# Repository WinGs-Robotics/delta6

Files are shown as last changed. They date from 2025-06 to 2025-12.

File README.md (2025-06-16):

# Delta6: 6-DOF Force-Sensing Flexible End-Effector

<div align="center">
  Delta6 in Action
</div>

---

## 🚀 Overview

**Delta6** is a **low-cost**, **lightweight**, and **easy-to-assemble** 6-degree-of-freedom (6-DOF) flexible end-effector. Built upon an innovative modified Delta parallel mechanism, it integrates:

- **Six antagonistic spring units** for high-resolution force sensing.
- Real-time multi-axis force and displacement measurements.
- Built-in analytical compensation algorithms, correcting for imperfections from **3D-printed parts** and **commercial springs**.

Its inherent compliance makes Delta6 ideal for interactive tasks such as human–robot collaboration, precision assembly, and delicate manipulation.

---

## 📐 Specifications

<div align="center">
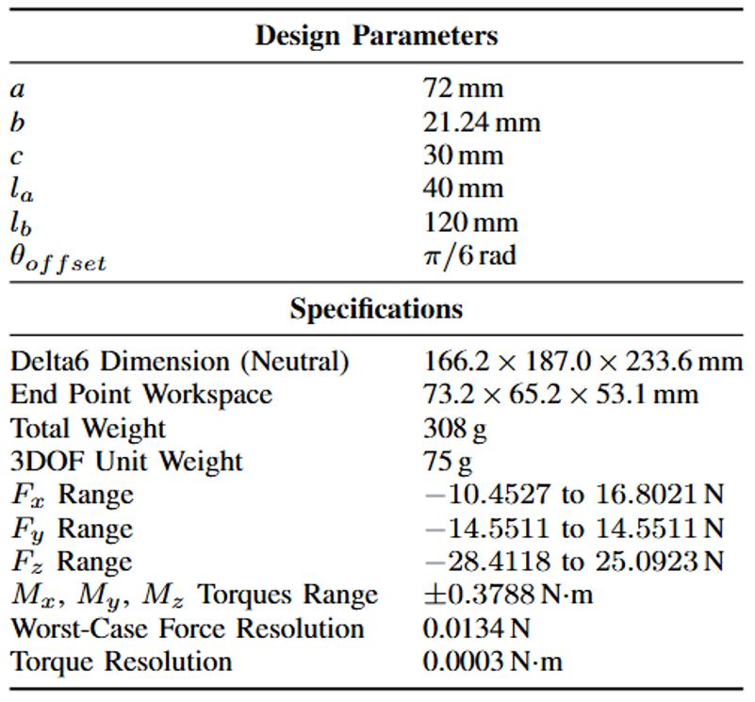
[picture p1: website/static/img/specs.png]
Delta6 Specifications
  
</div>

- **Compact & Lightweight:** ~170 × 190 × 235 mm, < 310 grams.
- **Operational Workspace:** Tens of millimeters range in all directions.
- **Force & Torque:** ±15 N forces, ±0.4 N·m torques.
- **High Precision:** Resolution down to hundredths of a newton and thousandths of a newton-meter.

---

## 📋 Bill of Materials

| Component | Quantity | Unit Cost (USD) | Subtotal (USD) |
|---|:---:|:---:|---:|
| PLA Filament (200 g) | 1 | 3.00 | **3.00** |
| Arduino Nano Every | 1 | 13.00 | **13.00** |
| M2 Tie-Rod Ball Ends | 12 | 1.00 | **12.00** |
| M2 × 100 mm Threaded Rods | 6 | 2.00 | **12.00** |
| Mn-Steel Door Handle Springs | 12 | 2.00 | **24.00** |
| ERCK-05 SPI 14-bit Magnetic Encoders | 6 | 43.00 | **258.00** |
| 15 × 21 × 4 mm Ball Bearing | 1 | 1.00 | **1.00** |
| 8 × 12 × 3.5 mm Ball Bearings | 10 | 1.00 | **10.00** |
| Wires, Connectors & Fasteners | Various  | 1.00 | **1.00** |
| **Total Cost** | | | **US $334.00** |

---

## 🔓 Open-Source Highlights

### 🧠 Analytical Force Estimation
Effortlessly translate encoder readings into a **complete 6-DOF wrench**, requiring simple calibration and enabling high-frequency computation on standard microcontrollers or PCs.

### ⚙️ Modular & 3D-Printable
Engineered specifically for **consumer-grade PLA printers**, Delta6 features only **13 unique, symmetrically-arranged parts**, simplifying both manufacturing and assembly.

### 💰 Cost-Effective
Prototype costs are approximately **$300 USD**, with further reductions achievable through bulk production and custom PCB integration.

---

## 🚧 Getting Started

Detailed purchase links, comprehensive CAD models, intuitive assembly instructions, firmware, and a Python SDK are available in DOC website. Start building your Delta6 today and explore the possibilities of affordable, precise robotic interaction!

---

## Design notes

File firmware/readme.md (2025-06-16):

# Delta6 Firmware Communication Protocol

## Overview

This document describes the communication protocol between the PC (host) and the Delta6 end-effector firmware, including command formats, response formats, functional descriptions, and error handling mechanisms.

---

## 📱 Command Frame Format (PC → Firmware)

| Field | Description |
|:---:|:---:|
| Start Byte | `0xAA`, indicates the beginning of a frame |
| Command Byte | Operation code (Calibration or Read) |
| Checksum | Simple additive checksum |

**Command Byte Values**:
- `0x01`: **Calibration Command**
- `0x02`: **Read Command**

**Checksum**:  
The checksum is calculated as the simple sum of the start byte and command byte, modulo 256.

---

## 📥 Response Frame Format (Firmware → PC)

| Field | Description |
|:---:|:---:|
| Start Byte | `0xAA`, indicates the beginning of a frame |
| Sensor 1 Data | 2 bytes (signed integer, calibrated angle) |
| ... | ... |
| Sensor 6 Data | 2 bytes (signed integer, calibrated angle) |
| Error Flags | 1 byte (each bit indicates a sensor read error) |
| Checksum | 1 byte (simple additive checksum) |

**Sensor Data**:  
Each sensor outputs a signed 2-byte integer representing the calibrated angle.

**Error Flags**:  
- 1 byte total.
- Each bit corresponds to one sensor.  
  If a bit is `1`, the corresponding sensor encountered a read error.

**Checksum**:  
The checksum is calculated as the simple sum of all bytes after the start byte.

---

## 🔧 Functional Details

### Calibration Function

Upon receiving a **Calibration Command (0x01)**, the firmware:
- Reads the current angle values from all sensors.
- Stores them as calibration offsets.

### Read Function

Upon receiving a **Read Command (0x02)**, the firmware:
- Reads the current sensor values.
- Subtracts calibration offsets.
- Sends the calibrated values along with error flags and checksum.

### Error Handling

In the `updatePositions()` function:
- If a sensor read returns `-1`, the corresponding error flag bit is set.
- Errors are reported in the response frame's error flag byte.

### Data Integrity

- A simple additive checksum ensures data integrity.
- CRC can be used for more robust error detection if needed.

---

## 📌 Notes

- Start byte `0xAA` must always be included at the beginning of each frame.
- Only two commands (`0x01` and `0x02`) are currently supported.
- All multi-byte data are transmitted **big-endian** unless otherwise specified.

---

✅ **This communication protocol ensures reliable, efficient interaction between the PC and the Delta6 firmware, enabling robust 6-DOF force-sensing operations.**

## Acknowledgment

**Some parts of the documentation and code were assisted by language models (OpenAI's ChatGPT) during their initial drafting. All content was subsequently reviewed and verified by the project authors.**

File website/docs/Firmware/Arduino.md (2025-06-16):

---
sidebar_position: 1
---

# Microcontroller Setup 🖥️

This section explains how to set up the Arduino Nano Every and prepare the Python environment for the Delta6 system.

> 📦 **Firmware Repository:**  
> The firmware code for the Arduino Nano Every is available here:  
> [Delta6 Firmware on GitHub](https://github.com/ttopeor/Delta6_Doc/tree/main/firmware)

---

## 1. Download the Repository

Clone the Delta6 project repository:

```bash
git clone https://github.com/ttopeor/Delta6_Doc.git
```

---

## 2. Create and Activate Python Environment

Navigate to the Python SDK folder:

```bash
cd delta6_python_SDK
```

> 📌 **Tip:** Ensure that Python 3.12 is installed on your system.

Create a virtual environment:

```bash
python3.12 -m venv venv
```

Activate the virtual environment:

- **On Ubuntu:**

  ```bash
  source venv/bin/activate
  ```

- **On Windows:**
  ```bash
  source venv/Scripts/activate
  ```

Install all required dependencies:

```bash
pip install -e .
```

---

## 3. Burn Firmware to Arduino

Check the COM port (for example `/dev/ttyACM0` on Linux) where your Arduino Nano Every is connected.  
Then run the following command:

```bash
python burn_firmware.py --port /dev/ttyACM0
```

> 🧩 **Tip:** Adjust the `--port` argument according to your specific system setup.

---

## 4. Verify Operation

Run the example script:

```bash
python example.py --port /dev/ttyACM0
```

If successful, a window should pop up similar to:

<p align="center">
  Online Evaluation
</p>

The coordinate system is defined as follows:

<p align="center">
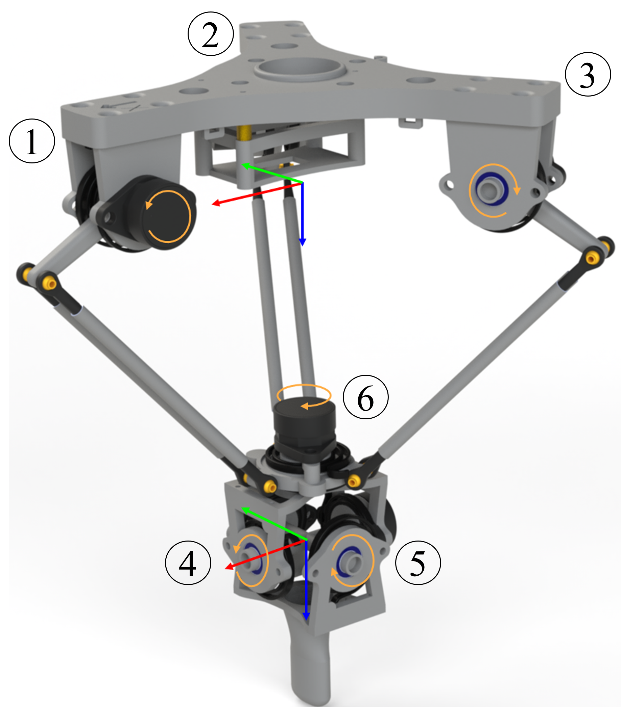
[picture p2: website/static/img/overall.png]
Coordinate System Definition
  
</p>

---

🎯 **Congratulations!**  
Your microcontroller setup is complete, and the Delta6 system is ready for further testing and calibration.

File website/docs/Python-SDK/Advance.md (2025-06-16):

---
sidebar_position: 3
---

# Advanced Usage 🚀

This section provides a detailed explanation of the **DeltaRobot** class located at:

```bash
delta6_python_SDK/kinematics/delta6_analytics.py
```

The `DeltaRobot` class offers methods for advanced kinematics calculations, force estimation, and internal torque computations for the Delta6 system.

---

## 1. Initialization

Create a Delta6 robot model by specifying its physical parameters:

```python
from kinematics.delta6_analytics import DeltaRobot

delta6 = DeltaRobot(
    short_arm_length=40.0,         # Length of the short (servo) arm [mm]
    parallel_arm_length=120.0,     # Length of the parallel (linkage) arm [mm]
    base_radius=72.0,              # Radius of the fixed base [mm]
    end_effector_radius=21.24      # Radius of the moving end-effector platform [mm]
)
```

> 📌 **Note:** Default values are already tuned for the Delta6 system.

---

## 2. Main Interfaces

### 2.1 Updating Joint States

You can update the robot's internal state (angles and torques) using:

```python
delta6.update(theta1, theta2, theta3, theta4, theta5, theta6)
```

- `theta1` to `theta6` are joint angles (in radians).
- Internally, it updates both joint angles and spring torques.

---

### 2.2 Forward Kinematics

To compute the end-effector pose (position and orientation) from joint angles:

```python
pose = delta6.get_FK_result()
```

Returns a tuple:

```
(x, y, z, roll, pitch, yaw)
```
- All positions are in meters (m).
- All rotations are in radians (rad).

> 📌 **Tip:** The Delta6 model internally handles the mechanical offsets and link geometry.

---

### 2.3 Inverse Kinematics

To solve the required joint angles for a given target pose:

```python
thetas = delta6.inverse_kinematics(x, y, z, roll, pitch, yaw)
```

- Input: desired position (m) and orientation (rad).
- Output: six joint angles `(theta1, theta2, theta3, theta4, theta5, theta6)`.
- Returns `None` if the target is unreachable.

---

### 2.4 Force Estimation

To estimate the end-effector force/torque from spring readings:

```python
force = delta6.get_end_force()
```

Returns a tuple:

```
(Fx, Fy, Fz, Mx, My, Mz)
```
- Forces are in Newtons (N).
- Moments are in Newton-meters (Nm).

Internally, it uses the joint torques and geometric Jacobians.

---

### 2.5 Force-to-Torque Mapping

Given a desired force vector at the end-effector, you can calculate the required torques:

```python
torques = delta6.calculate_torque_123(Fx_target, Fy_target, Fz_target)
```

Useful for simulating force control.

---

### 2.6 Force-to-Pose Mapping

Given a full 6-DOF wrench `(Fx, Fy, Fz, Mx, My, Mz)`, estimate the corresponding pose:

```python
pose = delta6.calculate_euler_pose(Fx, Fy, Fz, Mx, My, Mz)
```

Returns:

```
(x, y, z, roll, pitch, yaw)
```

This is useful for **force-sensitive end-effector control** based on spring torque feedback.

---

## 3. Internal Model Details

> ⚙️ **Mechanics:**
> 
> - The Delta6 kinematics assumes 3 symmetric legs.
> - It internally applies mechanical z-offset corrections.
> - Rotations are handled using **scipy.spatial.transform** Euler conversion utilities.
> 
> - Forces are estimated based on spring extension/compression, taking into account the Delta geometry.

---

## 4. Summary

| Function | Purpose |
| :--- | :--- |
| `update()` | Update joint angles and compute torques |
| `get_FK_result()` | Compute end-effector pose from joint states |
| `inverse_kinematics()` | Solve joint states from target pose |
| `get_end_force()` | Estimate forces and moments |
| `calculate_torque_123()` | Map desired forces to spring torques |
| `calculate_euler_pose()` | Map desired forces/moments to end-effector pose |

---

🎯 **Advanced Tip:**  
You can combine real-time encoder readings + `update()` + `get_end_force()` to build a **real-time force estimation loop**, enabling force-controlled teleoperation or haptic feedback applications.

---

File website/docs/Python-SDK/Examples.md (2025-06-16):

---
sidebar_position: 2
---

# Quick Start Examples 💡

This section provides a quick guide on how to run a basic real-time loop using the Delta6 Python SDK.

The example script is located at:

```bash
delta6_python_SDK/example.py
```

---

## 1. Purpose of This Example

The `example.py` script demonstrates:

- Calibrating the sensors
- Reading encoder data in real-time
- Computing forward kinematics
- Visualizing the estimated end-effector forces

It serves as a **minimal starting point** to verify that all hardware and software are working correctly.

---

## 2. How to Run

Activate the Python environment first:

```bash
# On Ubuntu
source venv/bin/activate

# On Windows
source venv/Scripts/activate
```

Then run the example:

```bash
python delta6_python_SDK/example.py --port /dev/ttyACM0 --freq 50
```

- Replace `/dev/ttyACM0` with your Arduino Nano Every's actual port.
- `--freq` controls the loop frequency (default is 50 Hz).

---

## 3. How It Works

The script defines a `MainLoop` class (derived from `RTLoop`) to organize initialization, looping, and shutdown behaviors.

The full execution flow is as follows:

### Initialization (`setup()` method)

1️⃣ **Sensor Calibration**  
   - Code: `sensor_calibration(nano_port=self.nano_port)`
   - Prompts the user to move the device to a neutral position and records zero offsets.

2️⃣ **Start Encoder Reading Loop**  
   - Code: `self.read_encoder_loop = ReadEncoderLoop(nano_port=self.nano_port, encoder_dir=ENCODER_DIR)`
   - Encoder angles are read asynchronously at high frequency.

3️⃣ **Initialize Delta6 Kinematics Model**  
   - Code: `self.Delta6 = DeltaRobot()`
   - Creates a new DeltaRobot instance to calculate forward kinematics from encoder readings.

4️⃣ **Start Force Visualizer**  
   - Code: 
     ```python
     self.force_visualizer = ForceVisualizer(...)
     self.force_visualizer.start()
     ```
   - A real-time window opens to display the estimated end-effector forces.

5️⃣ **Start Real-Time Loop Spin**  
   - Code: `super().setup()`
   - Prepares the internal threading/timing logic to start looping.

---

### Main Loop (`loop()` method)

Each real-time cycle (`50 Hz` by default):

- **Read encoder data**  
  Code: `encoder_reading = self.read_encoder_loop.get_encoder_reading()`

- **Update Delta6 model**  
  Code: `self.Delta6.update(*encoder_reading)`

- **Compute and print end-effector pose**  
  Code: 
  ```python
  delta6_pose_reading = self.Delta6.get_FK_result()
  print(f"End-effector pose (x, y, z, roll, pitch, yaw): {delta6_pose_reading}")
  ```

- **Update the force visualizer**  
  Code:
  ```python
  delta6_end_force = self.Delta6.get_end_force()
  self.force_visualizer.update_forces([delta6_end_force])
  ```

Example console output:

```
End-effector pose (x, y, z, roll, pitch, yaw): [0.012, 0.005, 0.230, 0.01, -0.02, 0.00]
```

---

### Shutdown (`shutdown()` method)

When exiting the program (e.g., Ctrl+C):

- **Stop the force visualizer**  
  Code: `self.force_visualizer.stop()`

- **Terminate real-time loop cleanly**  
  Code: `super().shutdown()`

- **Print shutdown confirmation**  
  Code: `print("Force visualizer shutdown.")`

---

## 4. Notes

> 📌 **Tip:**  
You can adjust the `--freq` parameter to higher values (e.g., 100 Hz) for faster updates, depending on your PC performance.

> ⚡ **Warning:**  
Always run sensor calibration before starting meaningful data collection, to avoid force/pose estimation errors.

---

🎯 **Congratulations!**  
By running this quick start example, you have verified that your Delta6 system hardware and software are properly set up!

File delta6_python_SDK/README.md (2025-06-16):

## 📘 Quick Start Guide

### 1. Setup Python Environment
```bash
cd delta6_python_SDK
python3.12 -m venv venv

# Activate virtual environment
# On Ubuntu
source venv/bin/activate

# On Windows
source venv/Scripts/activate

pip install -e .
```

### 2. Burn Firmware to Arduino Nano
```bash
python burn_firmware.py --port /dev/ttyACM0
```

### 3. Run Example
```bash
python example.py --port /dev/ttyACM0
```

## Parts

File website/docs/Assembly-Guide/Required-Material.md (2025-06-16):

---
sidebar_position: 1
---

# Required Material & Tools 📦

This page provides a detailed list of all required materials and tools to assemble the Delta6 system.

---

## 1. 3D Printed Parts 🖨️

All CAD files are available at:  
🔗 [Delta6 CAD Repository](https://github.com/ttopeor/Delta6_Doc/tree/main/CAD)

<p align="center">
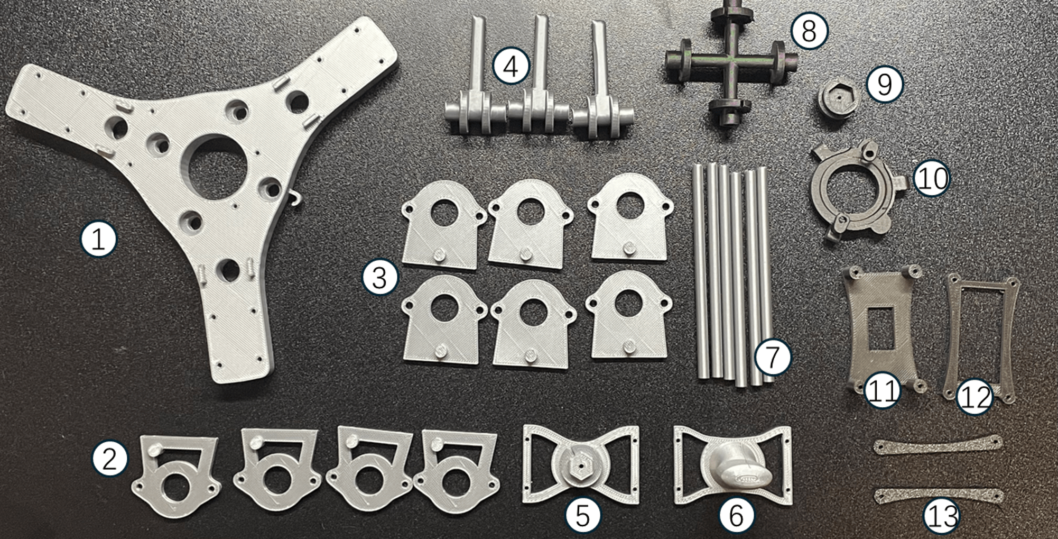
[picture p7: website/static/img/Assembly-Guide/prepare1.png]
3D Printed Parts
  
</p>

The following parts need to be 3D printed using **PLA** material:

| No. | Part Name | File Name | Quantity |
| :-: | :--- | :--- | :--- |
|  1  | Arm Mount | `arm_mount.STL` | 1 |
|  2  | Bearing Housing (Roll/Pitch) | `bearing_housing_roll_pitch.STL` | 4 |
|  3  | Bearing Housing (XYZ) | `bearing_housing_xyz.STL` | 6 |
|  4  | Limb | `limb.STL` | 3 |
|  5  | Universal Joint (Upper) | `universal_joint_upper.STL` | 1 |
|  6  | Universal Joint (Lower) | `universal_joint_lower.STL` | 1 |
|  7  | Long M2 Cover | `long_m2_cover.STL` | 6 |
|  8  | Shaft (Roll/Pitch) | `shaft_roll_pitch.STL` | 1 |
|  9  | Shaft (Yaw) | `shaft_yaw.STL` | 1 |
| 10  | Bearing Housing (Yaw) | `bearing_housing_yaw.STL` | 1 |
| 11  | Power Distributor Holder | `power_distributor_holder.STL` | 1 |
| 12  | Nano Holder 1 | `nano_holder_1.STL` | 1 |
| 13  | Nano Holder 2 | `nano_holder_2.STL` | 1 |

> 📌 **Note:** Please ensure sufficient print quality (recommended infill = 100%) for mechanical robustness.

---

## 2. Standard Components 🔩

<p align="center">
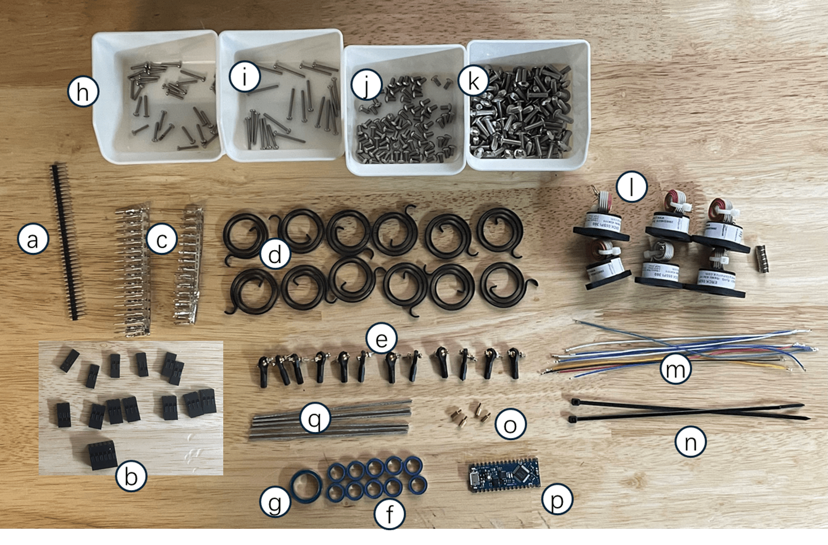
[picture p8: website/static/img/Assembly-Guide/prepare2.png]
Standard Parts Overview
  
</p>

The following standard parts must be prepared:

| No. | Component | Link | Quantity |
| :-- | :--- | :--- | :--- |
| a | GPIO Pins | [Amazon](https://www.amazon.com/MCIGICM-Header-2-45mm-Arduino-Connector/dp/B07PKKY8BX/) | 1 Row |
| b/c | 2.54mm Connector Kit | [Amazon](https://www.amazon.com/dp/B077X8XV2J) | 2-pin (6 pcs), 3-pin (7 pcs), 2×6-pin (1 pc) |
| d | Coil Springs | [Amazon](https://www.amazon.com/dp/B07ZVJR1HM) | 6 pcs |
| e | M2 Ball Heads | [Amazon](https://www.amazon.com/dp/B0BJFLD8RH) | 12 pcs |
| f | Bearings (8×12×3.5mm) | [Amazon](https://www.amazon.com/dp/B09L13V474) | 10 pcs |
| g | Bearings (15×21×4mm) | [Amazon](https://www.amazon.com/dp/B09L11PJJN) | 1 pc |
| h | M2×8mm Screws | [Amazon](https://www.amazon.com/iExcell-Stainless-Steel-Socket-Screws/dp/B094NVN97P/) | As needed |
| i | M2×20mm Screws | [Amazon](https://www.amazon.com/iexcell-Stainless-Steel-Socket-Screws/dp/B0B4VS4PCK/) | As needed |
| j | M3×6mm Screws | [Amazon](https://www.amazon.com/Uxcell-a15070200ux0064-Stainless-Phillips-Screws/dp/B012TE12CY/) | As needed |
| k | M4×6mm Screws | [Amazon](https://www.amazon.com/uxcell-Machine-Phillips-Stainless-Fasteners/dp/B07MF33MRJ) | As needed |
| l | ERCK 05SPI 360 Encoders | [P3 America](https://p3america.com/erck-05spi-360/) | 6 pcs |
| m | Colored 28 AWG Cables | [Amazon](https://www.amazon.com/Keszoox-Connector-Pre-Crimped-Kit%EF%BC%8CTotal-Connectors/dp/B09F3TMG52/) | As needed |
| n | Cable Ties | [Amazon](https://www.amazon.com/HAVE-ME-TD-Cable-Ties/dp/B08TVLYB3Q/) | As needed |
| o | M2 Brass Standoffs | [Amazon](https://www.amazon.com/uxcell-Thread-Standoff-Spacer-Pillar/dp/B07H3V31GY/) | 4 pcs |
| p | Arduino Nano Every | [Amazon](https://www.amazon.com/Arduino-Nano-Every-Boards-Pack/dp/B07YQ56B6Q/) | 1 pc |
| q | M2×100mm Fully Threaded Rods | [Amazon](https://www.amazon.com/dp/B08CGNXQVN) | 6 pcs |

> 📦 **Tip:** Ordering extra quantities for small components (screws, pins) is highly recommended.

---

## 3. Recommended Tools 🔧

<p align="center">
  Recommended Tools
</p>

While not all tools are mandatory, having them available will significantly ease the assembly process:

### 🔌 Electronics Tools

- Multimeter
- Breadboard
- Jumper wires
- Desoldering pump
- Tweezers
- Crimping tool
- Wire stripper
- Hobby knife
- Heat shrink tubing
- Heat gun
- Soldering iron

### ⚙️ Mechanical Tools

- Pliers
- Electric drill
- Bench vise
- Screwdrivers (various sizes)
- Strong adhesive (e.g., super glue)

> ⚡ **Safety Tip:** Always work in a ventilated area when soldering or using strong adhesives!

---

**Next:** Once all materials and tools are prepared, you are ready to start the assembly process! 🚀

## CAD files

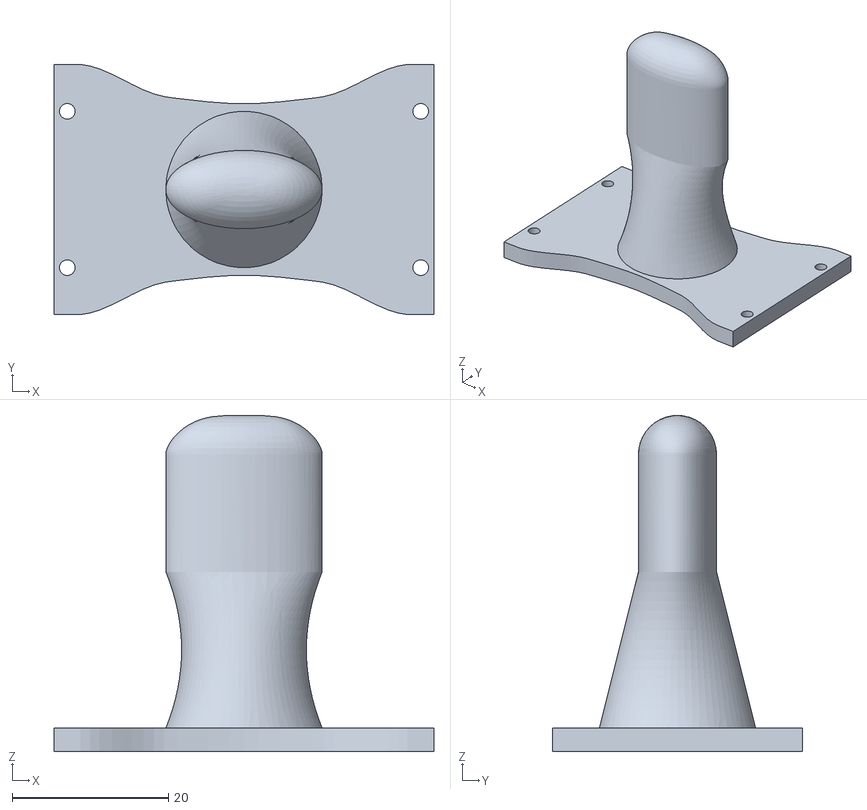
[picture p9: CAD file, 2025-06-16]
CAD/universal_joint_lower.STL
48.6 x 32.0 x 43.0

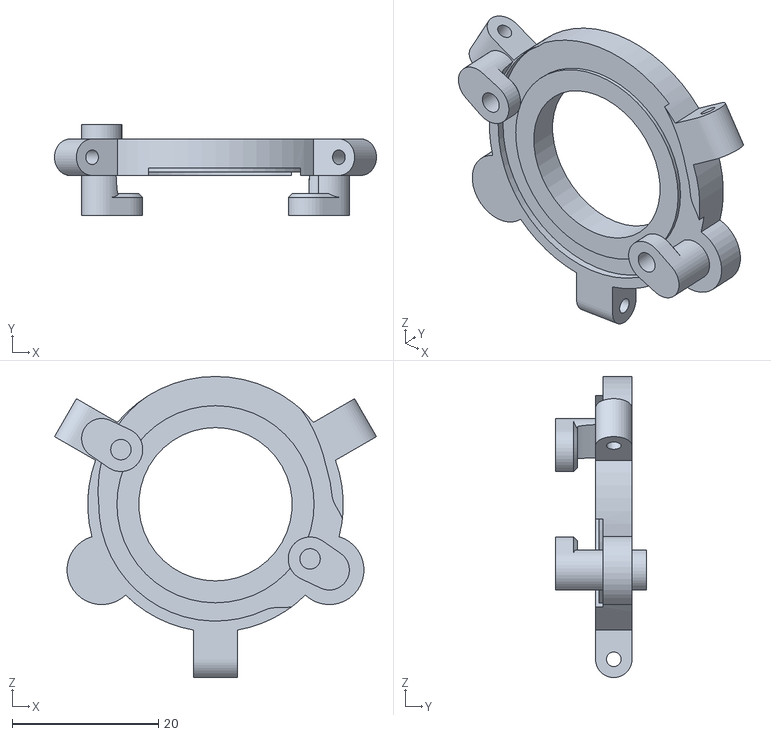
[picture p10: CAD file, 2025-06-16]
CAD/bearing_housing_yaw.STL
44.1 x 12.5 x 41.2

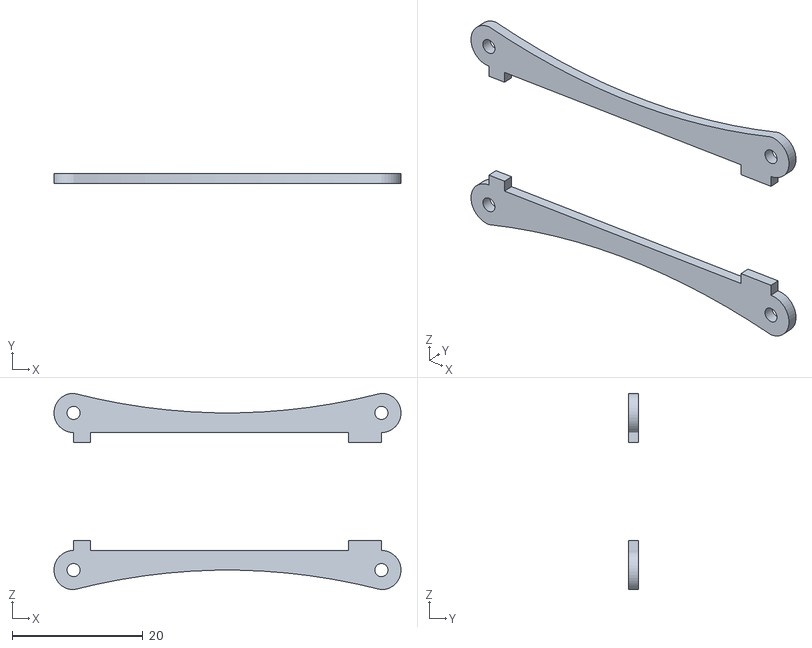
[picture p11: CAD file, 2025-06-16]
CAD/nano_holder_2.STL
53.0 x 1.50 x 30.0

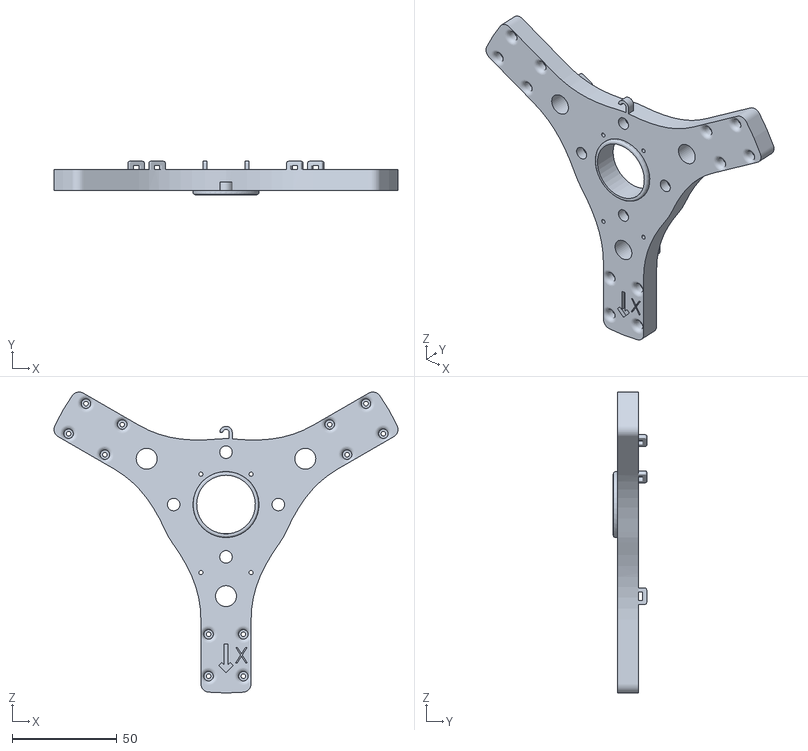
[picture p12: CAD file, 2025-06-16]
CAD/arm_mount.STL
164.3 x 16.0 x 143.7

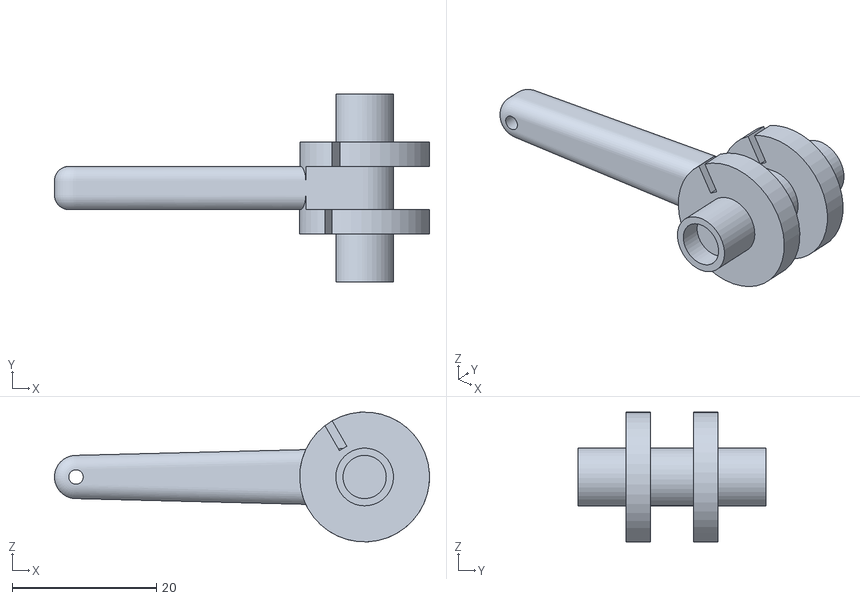
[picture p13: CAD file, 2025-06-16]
CAD/limb.STL
52.0 x 26.0 x 18.0

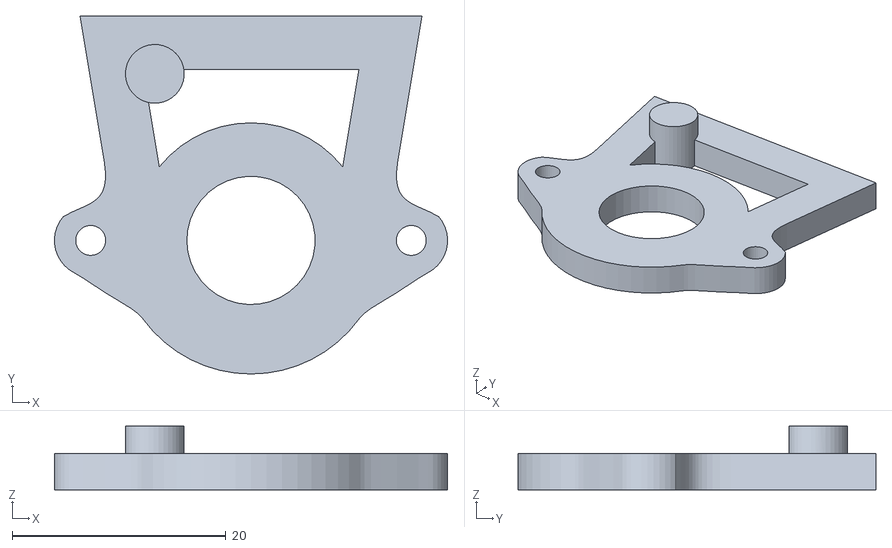
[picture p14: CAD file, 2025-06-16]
CAD/bearing_housing_roll_pitch.STL
36.8 x 33.5 x 5.95

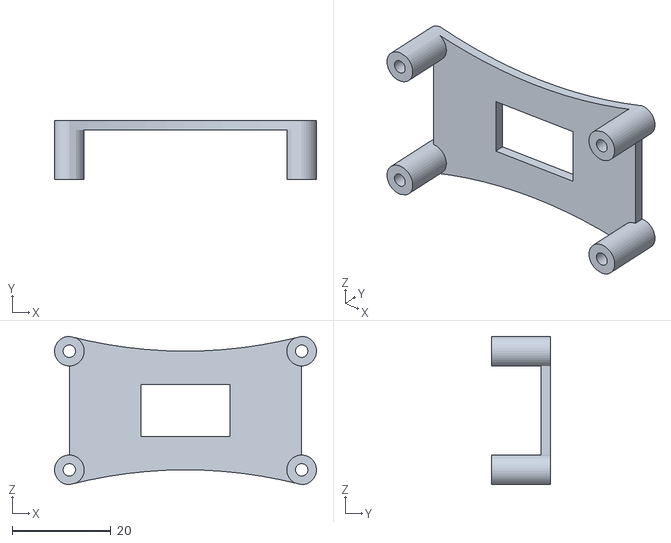
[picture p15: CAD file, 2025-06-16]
CAD/power_distributor_holder.STL
53.0 x 12.0 x 30.0

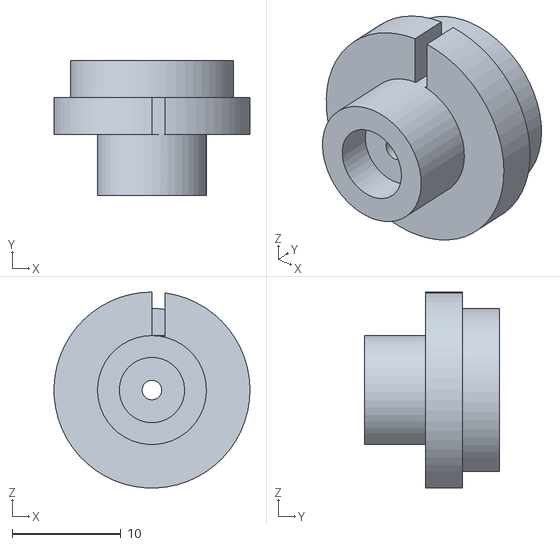
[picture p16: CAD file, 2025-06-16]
CAD/shaft_yaw.STL
18.0 x 12.4 x 18.0

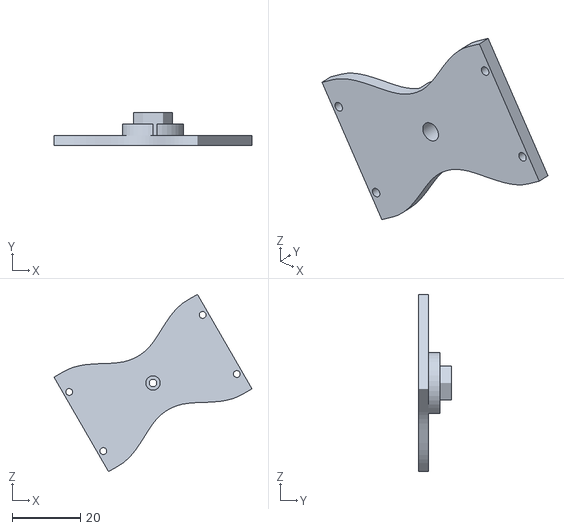
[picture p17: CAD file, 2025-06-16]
CAD/universal_joint_upper.STL
58.1 x 9.80 x 52.0

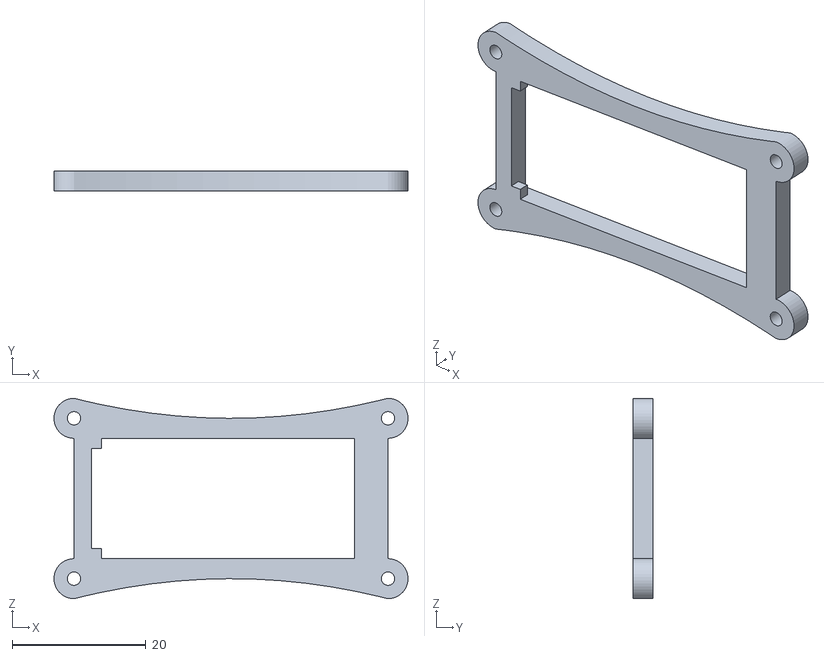
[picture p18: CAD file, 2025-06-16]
CAD/nano_holder_1.STL
53.0 x 3.00 x 30.0

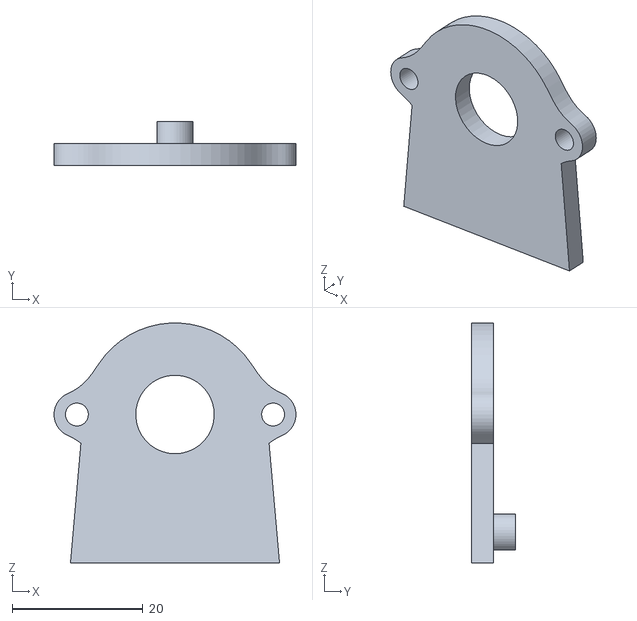
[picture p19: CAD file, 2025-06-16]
CAD/bearing_housing_xyz.STL
37.0 x 6.80 x 36.7

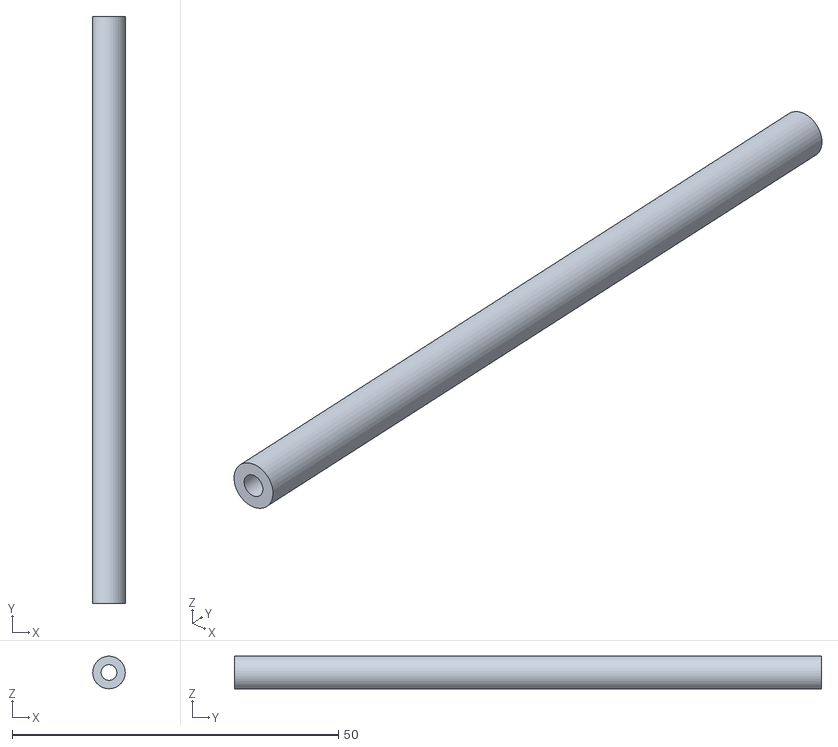
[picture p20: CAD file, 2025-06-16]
CAD/long_m2_cover.STL
5.00 x 90.0 x 5.00

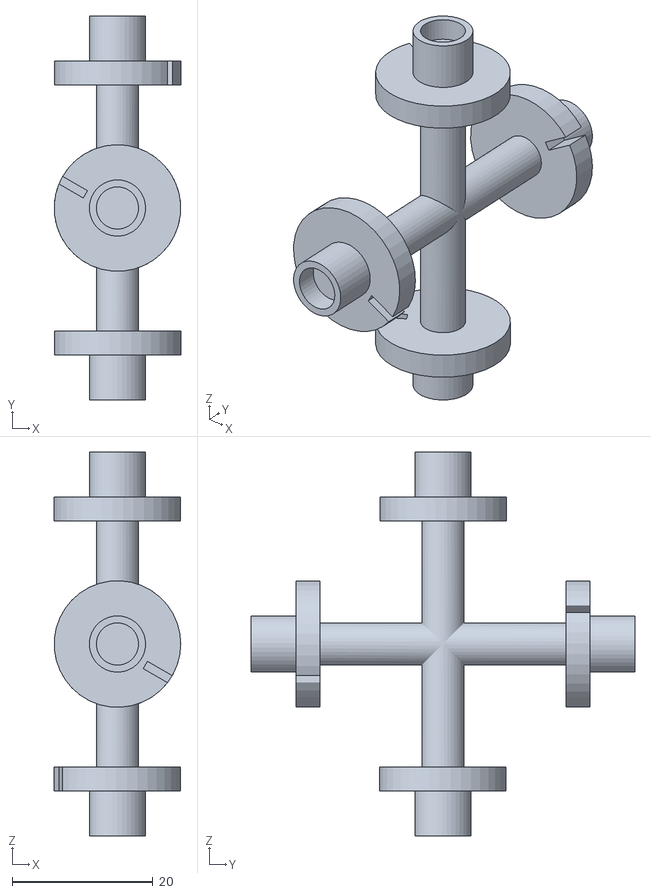
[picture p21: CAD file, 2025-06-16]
CAD/shaft_roll_pitch.STL
18.0 x 54.6 x 54.6

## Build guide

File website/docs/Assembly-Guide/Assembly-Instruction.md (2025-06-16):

---
sidebar_position: 3
---

# Step-by-Step Assembly Instructions 🛠️

This section provides a detailed, step-by-step guide for assembling the Delta6 mechanical and electronic modules.

---

## 1. Microcontroller Module Assembly

<p align="center">
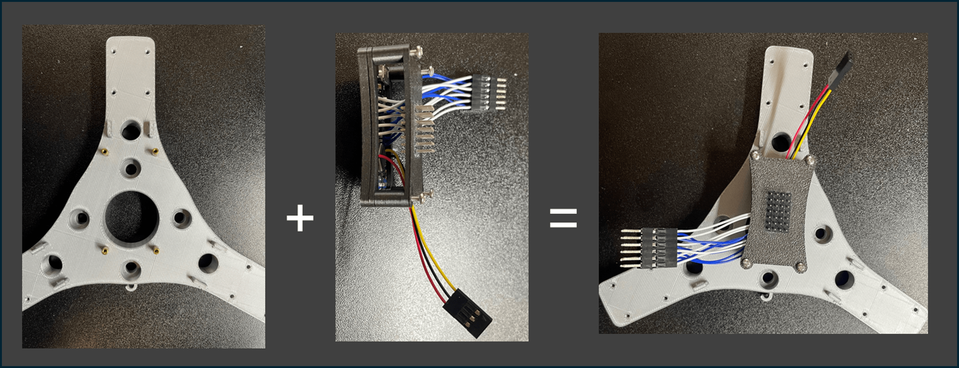
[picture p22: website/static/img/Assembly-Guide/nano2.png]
Microcontroller Assembly
  
</p>

**Steps:**

1️⃣ Use **4× M2 standoffs** (**o**) and **4× M2×20mm screws** to mount the following parts together in a stack:

- Nano Holder 1 (**12**)
- Nano Holder 2 (**13**)
- Power Distributor Holder (**11**)

2️⃣ Attach the stacked module onto the **Arm Mount** (**1**) as shown.

3️⃣ Carefully arrange the wiring as indicated in the figure to avoid future interference.

> 📌 **Note:** Keep all wires as organized as possible following the reference image.

---

## 2. Limb and Spring Assembly

<p align="center">
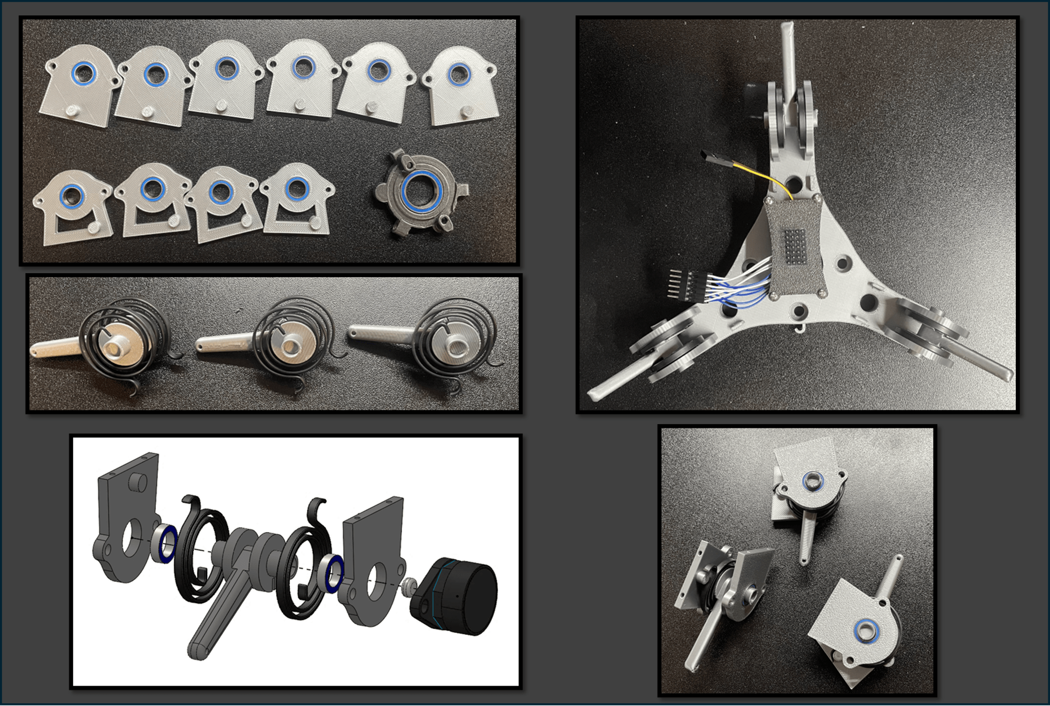
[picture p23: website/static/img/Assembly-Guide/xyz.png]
Limb and Spring Assembly
  
</p>

**Steps:**

1️⃣ Press-fit the bearings (**f**, **g**) into:

- Bearing Housing (XYZ) (**3**)
- Bearing Housing (Roll/Pitch) (**2**)
- Bearing Housing (Yaw) (**10**)

> 🧩 **Tip:** If the fit is loose, secure the bearings with a small amount of strong adhesive.

2️⃣ Press the **springs (d)** onto each **Limb (4)** as shown, forming three spring-loaded limbs.

3️⃣ Assemble the bearing housings together according to the figure.

4️⃣ Fix the limb structures onto the **Arm Mount (1)** using **M2×20mm screws**.

> 📸 After assembly, the structure should look exactly like the top-right image.

---

## 3. Universal Joint Module Assembly

<p align="center">
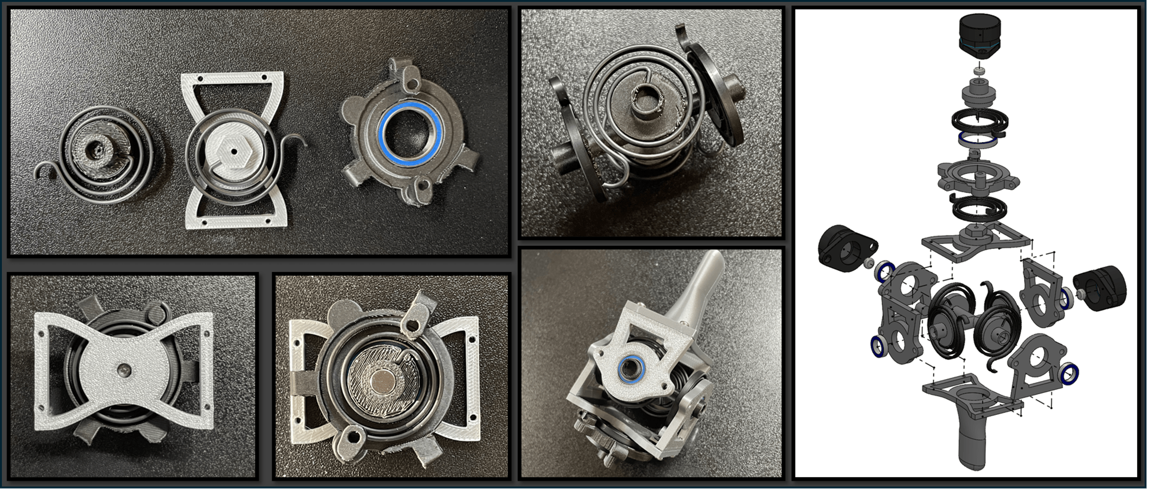
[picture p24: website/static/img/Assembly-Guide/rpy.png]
Universal Joint Assembly
  
</p>

**Steps:**

1️⃣ Install a spring (**d**) onto each of the following parts:

- Shaft (Yaw) (**9**)
- Universal Joint (Upper) (**5**)

Ensure the spring orientation strictly matches the figure.

2️⃣ Assemble the Shaft (Yaw), Universal Joint (Upper), and Universal Joint (Lower) (**6**) using an **M2×20mm screw**, aligning them as shown.

3️⃣ Press-fit a **circular magnet** into the top of Shaft (Yaw) (**9**) **before proceeding**, as this area will become inaccessible later.

4️⃣ Press-fit four springs onto the Shaft (Roll/Pitch) (**8**), matching the exact orientations shown in the figure.

5️⃣ Assemble the complete Roll-Pitch-Yaw spring mechanism.

6️⃣ Fix the Bearing Housing (Roll/Pitch) using **M2×8mm screws**.

> 📌 **Important:** Carefully follow the orientation shown to ensure proper force sensing directions.

---

## 4. Connecting Upper and Lower Assemblies

<p align="center">
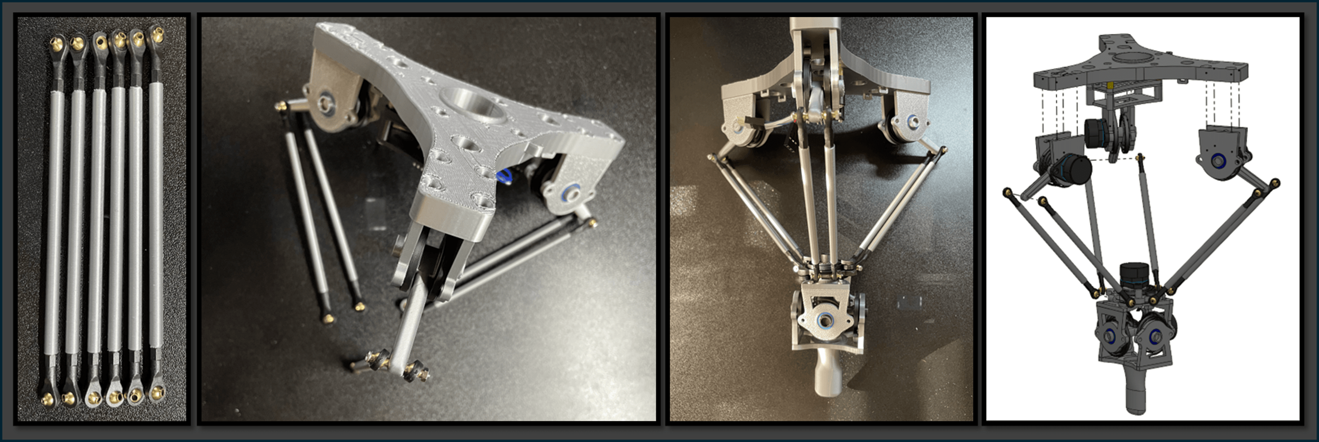
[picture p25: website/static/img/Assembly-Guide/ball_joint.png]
Linking Assembly
  
</p>

**Steps:**

1️⃣ Insert six **M2×100 rods (q)** into the **Long M2 Covers (7)**.

2️⃣ Attach an **M2 Ball Head (e)** to each end of the rods.

> 🎯 The Ball Heads must be **parallel** and the Long M2 Covers must be **secure**, with no looseness.

3️⃣ Pair the rods into groups of two and attach them to the **Limb modules (4)**.

4️⃣ Finally, connect the rods to the **Universal Joint Module** using **M2×20mm screws** and nuts.

> 📌 **Note:**  
> Ensure that the **relative orientation** between the Universal Joint and the Arm Mount (**1**) matches the figure exactly.  
> Incorrect installation will lead to misaligned force sensing axes.

---

## 5. Encoder Installation

<p align="center">
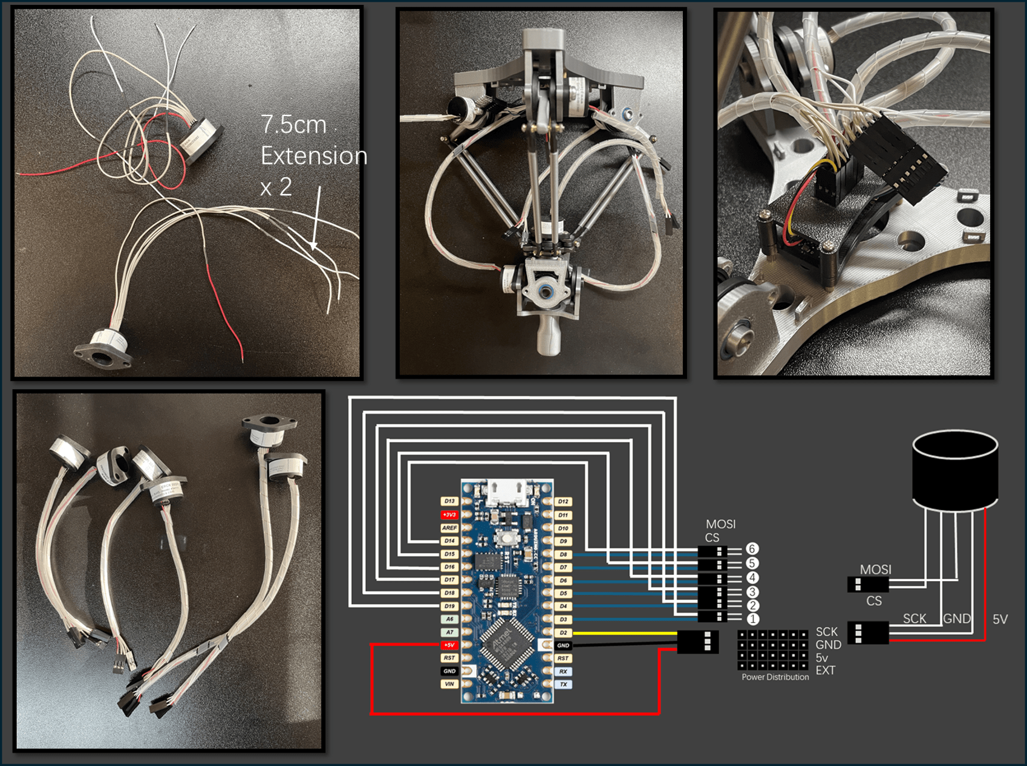
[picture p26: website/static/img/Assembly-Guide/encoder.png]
Encoder Installation
  
</p>

**Steps:**

1️⃣ Prepare six **ERCK 05SPI 360 Encoders (i)**.  
Extend the wires of two encoders by approximately **7.5 cm** using **Colored 28 AWG Cables (m)**.

2️⃣ Group and connect the wires as follows:

- **Group 1 (3-pin connector):** 5V → GND → SCK
- **Group 2 (2-pin connector):** MOSI → CS

> 🎨 **Wiring Order:**  
> The rightmost wire (red mark) is **5V**, followed by **GND**, then **SCK**, **MOSI**, and **CS** from right to left.

3️⃣ Install the six encoders to the positions shown in the diagram.  
Use:

- **M3×6mm screws** for general mounting
- **M4×6mm screws** for specific positions as indicated
- Encoders with **extended cables** should be installed at positions 4 and 5.

<p align="center">
  Overall Assembly
</p>

4️⃣ Final wiring:

- Insert 3-pin headers into the **Power Distribution Board**.
- Connect 2-pin headers to the **6×2 connector**.

**Final Encoder Pin Mapping:**

|  Encoder  | Chip Select (CS) | Data Input (MOSI) |
| :---: | :---: | :---: |
| Encoder 1 | D3 | D19 |
| Encoder 2 | D4 | D18 |
| Encoder 3 | D5 | D17 |
| Encoder 4 | D6 | D16 |
| Encoder 5 | D7 | D15 |
| Encoder 6 | D8 | D14 |

> 📌 **Reminder:**  
> Ensure that the wiring order is strictly followed to avoid communication errors.

---

🎉 **Congratulations!**  
You have successfully completed the mechanical and electronics assembly!  
You can now proceed to the next section: **Firmware Installation** 🚀

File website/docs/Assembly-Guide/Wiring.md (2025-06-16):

---
sidebar_position: 2
---

# Wiring and Electronics Assembly 🔌

> ℹ️ **Note:**  
> Throughout this document, items in parentheses (e.g., **(p)**) refer to their corresponding material list identifiers.

In this section, we will prepare the wiring and electronics for the Delta6 system.

The Arduino Nano Every (**p**) is used to parse SPI signals from the encoders (**i**) and communicate with the PC via serial at up to 100 Hz.  
For detailed communication protocol, please refer to the **Firmware** chapter.

---

## 1. Arduino Nano Wiring

<p align="center">
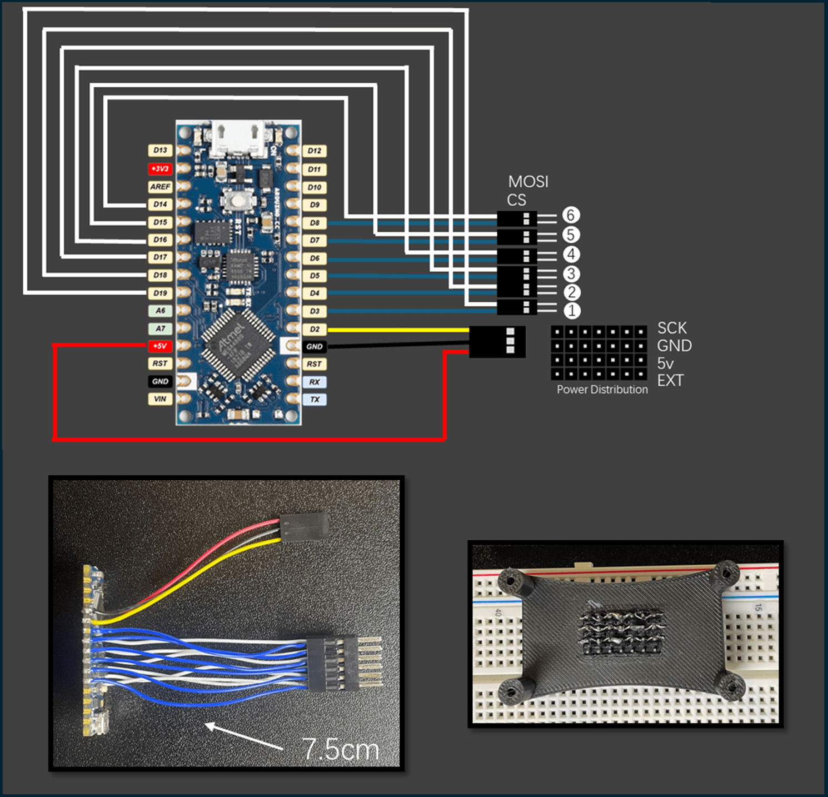
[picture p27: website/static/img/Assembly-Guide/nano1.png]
Arduino Nano Wiring
  
</p>

**Steps:**

1️⃣ Prepare colored **28 AWG** wires (**m**), each cut to approximately **7.5 cm** in length.  
2️⃣ Solder one end of each wire onto the Arduino Nano Every (**p**) according to the figure above.  
3️⃣ For the **5V**, **GND**, and **D2** pins, assemble them into a **3-pin female connector** (**b**, **c**).  
4️⃣ For the encoder SPI connections, match the pins as follows:

|  Encoder  | Chip Select (CS) | Data Input (MOSI) |
| :---: | :---: | :---: |
| Encoder 1 | D3 | D19 |
| Encoder 2 | D4 | D18 |
| Encoder 3 | D5 | D17 |
| Encoder 4 | D6 | D16 |
| Encoder 5 | D7 | D15 |
| Encoder 6 | D8 | D14 |

Each encoder uses a unique pair of pins: one **CS** pin for selection, and one **MOSI** pin for data input.

**Wiring Rule:**

- **D3–D19** pair → connect to Encoder 1
- **D4–D18** pair → connect to Encoder 2
- **D5–D17** pair → connect to Encoder 3
- **D6–D16** pair → connect to Encoder 4
- **D7–D15** pair → connect to Encoder 5
- **D8–D14** pair → connect to Encoder 6

> 📌 **Reminder:** Be careful to keep the CS and MOSI wires paired correctly, otherwise the encoders will not communicate properly.

---

## 2. Power Distribution Board Assembly

<p align="center">
  Power Distribution Board
</p>

**Steps:**

1️⃣ Prepare **GPIO pin headers** (**a**) and arrange them into a **4×7 grid**.  
2️⃣ It is recommended to insert the headers into a **breadboard** to maintain alignment during assembly.  
3️⃣ Once properly arranged, glue them together firmly using **strong adhesive**.  
4️⃣ Electrically connect the following rows individually:

- **SCK** row
- **GND** row
- **5V** row

This arrangement allows all six encoders to share the same **power supply** and **SCK signal**.

> ⚡ **Tip:** Always verify connections with a multimeter before powering up the system!

---

**Next Step:** After wiring is completed, proceed to connect the encoders and test the communication! 🚀

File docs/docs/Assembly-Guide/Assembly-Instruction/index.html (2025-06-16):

Skip to main content

On this page

# Step-by-Step Assembly Instructions 🛠️

This section provides a detailed, step-by-step guide for assembling the Delta6 mechanical and electronic modules.

## 1. Microcontroller Module Assembly

Microcontroller Assembly

Steps:

1️⃣ Use 4× M2 standoffs (o) and 4× M2×20mm screws to mount the following parts together in a stack:

- Nano Holder 1 (12)
- Nano Holder 2 (13)
- Power Distributor Holder (11)

2️⃣ Attach the stacked module onto the Arm Mount (1) as shown.

3️⃣ Carefully arrange the wiring as indicated in the figure to avoid future interference.

📌 Note: Keep all wires as organized as possible following the reference image.

## 2. Limb and Spring Assembly

Limb and Spring Assembly

Steps:

1️⃣ Press-fit the bearings (f, g) into:

- Bearing Housing (XYZ) (3)
- Bearing Housing (Roll/Pitch) (2)
- Bearing Housing (Yaw) (10)

🧩 Tip: If the fit is loose, secure the bearings with a small amount of strong adhesive.

2️⃣ Press the springs (d) onto each Limb (4) as shown, forming three spring-loaded limbs.

3️⃣ Assemble the bearing housings together according to the figure.

4️⃣ Fix the limb structures onto the Arm Mount (1) using M2×20mm screws.

📸 After assembly, the structure should look exactly like the top-right image.

## 3. Universal Joint Module Assembly

Universal Joint Assembly

Steps:

1️⃣ Install a spring (d) onto each of the following parts:

- Shaft (Yaw) (9)
- Universal Joint (Upper) (5)

Ensure the spring orientation strictly matches the figure.

2️⃣ Assemble the Shaft (Yaw), Universal Joint (Upper), and Universal Joint (Lower) (6) using an M2×20mm screw, aligning them as shown.

3️⃣ Press-fit a circular magnet into the top of Shaft (Yaw) (9) before proceeding, as this area will become inaccessible later.

4️⃣ Press-fit four springs onto the Shaft (Roll/Pitch) (8), matching the exact orientations shown in the figure.

5️⃣ Assemble the complete Roll-Pitch-Yaw spring mechanism.

6️⃣ Fix the Bearing Housing (Roll/Pitch) using M2×8mm screws.

📌 Important: Carefully follow the orientation shown to ensure proper force sensing directions.

## 4. Connecting Upper and Lower Assemblies

Linking Assembly

Steps:

1️⃣ Insert six M2×100 rods (q) into the Long M2 Covers (7).

2️⃣ Attach an M2 Ball Head (e) to each end of the rods.

🎯 The Ball Heads must be parallel and the Long M2 Covers must be secure, with no looseness.

3️⃣ Pair the rods into groups of two and attach them to the Limb modules (4).

4️⃣ Finally, connect the rods to the Universal Joint Module using M2×20mm screws and nuts.

📌 Note:
Ensure that the relative orientation between the Universal Joint and the Arm Mount (1) matches the figure exactly.
Incorrect installation will lead to misaligned force sensing axes.

## 5. Encoder Installation

Encoder Installation

Steps:

1️⃣ Prepare six ERCK 05SPI 360 Encoders (i).
Extend the wires of two encoders by approximately 7.5 cm using Colored 28 AWG Cables (m).

2️⃣ Group and connect the wires as follows:

- Group 1 (3-pin connector): 5V → GND → SCK
- Group 2 (2-pin connector): MOSI → CS

🎨 Wiring Order:
The rightmost wire (red mark) is 5V, followed by GND, then SCK, MOSI, and CS from right to left.

3️⃣ Install the six encoders to the positions shown in the diagram.
Use:

- M3×6mm screws for general mounting
- M4×6mm screws for specific positions as indicated
- Encoders with extended cables should be installed at positions 4 and 5.

Overall Assembly

4️⃣ Final wiring:

- Insert 3-pin headers into the Power Distribution Board.
- Connect 2-pin headers to the 6×2 connector.

Final Encoder Pin Mapping:

Encoder | Chip Select (CS) | Data Input (MOSI)
Encoder 1 | D3 | D19
Encoder 2 | D4 | D18
Encoder 3 | D5 | D17
Encoder 4 | D6 | D16
Encoder 5 | D7 | D15
Encoder 6 | D8 | D14

📌 Reminder:
Ensure that the wiring order is strictly followed to avoid communication errors.

🎉 Congratulations!
You have successfully completed the mechanical and electronics assembly!
You can now proceed to the next section: Firmware Installation 🚀

Edit this page (https://github.com/WinGs-Robotics/delta6/docs/Assembly-Guide/Assembly-Instruction.md)

- 1. Microcontroller Module Assembly
- 2. Limb and Spring Assembly
- 3. Universal Joint Module Assembly
- 4. Connecting Upper and Lower Assemblies
- 5. Encoder Installation

Docs

- Introduction

Community

- Website (https://www.wingsrobotics.com/)

More

- GitHub (https://github.com/WinGs-Robotics/delta6)

Copyright © 2025 WinGs Robotics.

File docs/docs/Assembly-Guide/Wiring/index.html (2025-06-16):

Skip to main content

On this page

# Wiring and Electronics Assembly 🔌

ℹ️ Note:
Throughout this document, items in parentheses (e.g., (p)) refer to their corresponding material list identifiers.

In this section, we will prepare the wiring and electronics for the Delta6 system.

The Arduino Nano Every (p) is used to parse SPI signals from the encoders (i) and communicate with the PC via serial at up to 100 Hz.
For detailed communication protocol, please refer to the Firmware chapter.

## 1. Arduino Nano Wiring

Arduino Nano Wiring

Steps:

1️⃣ Prepare colored 28 AWG wires (m), each cut to approximately 7.5 cm in length.
2️⃣ Solder one end of each wire onto the Arduino Nano Every (p) according to the figure above.
3️⃣ For the 5V, GND, and D2 pins, assemble them into a 3-pin female connector (b, c).
4️⃣ For the encoder SPI connections, match the pins as follows:

Encoder | Chip Select (CS) | Data Input (MOSI)
Encoder 1 | D3 | D19
Encoder 2 | D4 | D18
Encoder 3 | D5 | D17
Encoder 4 | D6 | D16
Encoder 5 | D7 | D15
Encoder 6 | D8 | D14

Each encoder uses a unique pair of pins: one CS pin for selection, and one MOSI pin for data input.

Wiring Rule:

- D3–D19 pair → connect to Encoder 1
- D4–D18 pair → connect to Encoder 2
- D5–D17 pair → connect to Encoder 3
- D6–D16 pair → connect to Encoder 4
- D7–D15 pair → connect to Encoder 5
- D8–D14 pair → connect to Encoder 6

📌 Reminder: Be careful to keep the CS and MOSI wires paired correctly, otherwise the encoders will not communicate properly.

## 2. Power Distribution Board Assembly

Power Distribution Board

Steps:

1️⃣ Prepare GPIO pin headers (a) and arrange them into a 4×7 grid.
2️⃣ It is recommended to insert the headers into a breadboard to maintain alignment during assembly.
3️⃣ Once properly arranged, glue them together firmly using strong adhesive.
4️⃣ Electrically connect the following rows individually:

- SCK row
- GND row
- 5V row

This arrangement allows all six encoders to share the same power supply and SCK signal.

⚡ Tip: Always verify connections with a multimeter before powering up the system!

Next Step: After wiring is completed, proceed to connect the encoders and test the communication! 🚀

Edit this page (https://github.com/WinGs-Robotics/delta6/docs/Assembly-Guide/Wiring.md)

- 1. Arduino Nano Wiring
- 2. Power Distribution Board Assembly

Docs

- Introduction

Community

- Website (https://www.wingsrobotics.com/)

More

- GitHub (https://github.com/WinGs-Robotics/delta6)

Copyright © 2025 WinGs Robotics.

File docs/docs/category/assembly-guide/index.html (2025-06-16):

Skip to main content

# Assembly Guide

Chapter 1: Assembly Guide

## 📄️ Required Material & Tools 📦

This page provides a detailed list of all required materials and tools to assemble the Delta6 system.

## 📄️ Wiring and Electronics Assembly 🔌

ℹ️ Note:

## 📄️ Step-by-Step Assembly Instructions 🛠️

This section provides a detailed, step-by-step guide for assembling the Delta6 mechanical and electronic modules.

Docs

- Introduction

Community

- Website (https://www.wingsrobotics.com/)

More

- GitHub (https://github.com/WinGs-Robotics/delta6)

Copyright © 2025 WinGs Robotics.

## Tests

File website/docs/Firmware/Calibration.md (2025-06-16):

---
sidebar_position: 3
---

# Calibration Procedure 🎯

This section explains how to calibrate the Delta6 sensors to ensure accurate force and displacement measurements.

The calibration script is located at:

```bash
delta6_python_SDK/sensor_interface/sensors_calibration.py
```

---

## 1. Preparation

Before starting the calibration:

- Ensure the Arduino Nano Every is properly connected and communicating.
- Complete the microcontroller setup steps described previously.
- Place the Delta6 device in a **neutral, relaxed position** without external forces.

---

## 2. Running the Calibration Script

Activate the Python virtual environment (if not already activated):

```bash
# On Ubuntu
source venv/bin/activate

# On Windows
source venv/Scripts/activate
```

Then run the calibration script:

```bash
python delta6_python_SDK/sensor_interface/sensors_calibration.py --port /dev/ttyACM0
```

Replace `/dev/ttyACM0` with the correct port for your Arduino Nano Every.

---

## 3. Calibration Procedure

The script will perform the following steps:

1️⃣ **Initial Reading:**  
The script reads and prints the current sensor data (in radians) to the terminal.

2️⃣ **User Prompt:**  
You will be prompted:

```
Please move the device to a natural position, then press Enter to calibrate...
```
Move the Delta6 device gently into its natural resting position, and press **Enter** when ready.

3️⃣ **Calibration Execution:**  
The system will record the resting values and perform internal calibration to zero out any offsets.

4️⃣ **Post-Calibration Reading:**  
The script will print the new sensor data, showing that the baseline has been adjusted.

5️⃣ **Resource Cleanup:**  
The script will automatically close the serial connection safely after calibration is complete.

---

## 4. Important Notes

> ⚡ **Tip:**  
Always calibrate the device **before each new session** to ensure consistent measurement accuracy.

> 📌 **Warning:**  
If you skip calibration, sensor readings may include offsets from mechanical relaxation or minor misalignments.

---

🎯 **Congratulations!**  
Once calibration is complete, your Delta6 system is ready for real-time data acquisition and experiments.

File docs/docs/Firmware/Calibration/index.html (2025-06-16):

Skip to main content

On this page

# Calibration Procedure 🎯

This section explains how to calibrate the Delta6 sensors to ensure accurate force and displacement measurements.

The calibration script is located at:

delta6_python_SDK/sensor_interface/sensors_calibration.py

## 1. Preparation

Before starting the calibration:

- Ensure the Arduino Nano Every is properly connected and communicating.
- Complete the microcontroller setup steps described previously.
- Place the Delta6 device in a neutral, relaxed position without external forces.

## 2. Running the Calibration Script

Activate the Python virtual environment (if not already activated):

# On Ubuntu
source venv/bin/activate

# On Windows
source venv/Scripts/activate

Then run the calibration script:

python delta6_python_SDK/sensor_interface/sensors_calibration.py --port /dev/ttyACM0

Replace /dev/ttyACM0 with the correct port for your Arduino Nano Every.

## 3. Calibration Procedure

The script will perform the following steps:

1️⃣ Initial Reading:
The script reads and prints the current sensor data (in radians) to the terminal.

2️⃣ User Prompt:
You will be prompted:

Please move the device to a natural position, then press Enter to calibrate...

Move the Delta6 device gently into its natural resting position, and press Enter when ready.

3️⃣ Calibration Execution:
The system will record the resting values and perform internal calibration to zero out any offsets.

4️⃣ Post-Calibration Reading:
The script will print the new sensor data, showing that the baseline has been adjusted.

5️⃣ Resource Cleanup:
The script will automatically close the serial connection safely after calibration is complete.

## 4. Important Notes

⚡ Tip:
Always calibrate the device before each new session to ensure consistent measurement accuracy.

📌 Warning:
If you skip calibration, sensor readings may include offsets from mechanical relaxation or minor misalignments.

🎯 Congratulations!
Once calibration is complete, your Delta6 system is ready for real-time data acquisition and experiments.

Edit this page (https://github.com/WinGs-Robotics/delta6/docs/Firmware/Calibration.md)

- 1. Preparation
- 2. Running the Calibration Script
- 3. Calibration Procedure
- 4. Important Notes

Docs

- Introduction

Community

- Website (https://www.wingsrobotics.com/)

More

- GitHub (https://github.com/WinGs-Robotics/delta6)

Copyright © 2025 WinGs Robotics.

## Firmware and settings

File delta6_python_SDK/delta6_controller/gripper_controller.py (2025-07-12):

from scservo_sdk.sts3023 import STS3032
from py_toolkit.rt_loop import RTLoop
import time


class Delta6GripperController(RTLoop):
    def __init__(self, motor_id: int, port: str, freq: float = 50, mode: str = "disable"):

        super().__init__(freq=freq)
        self.motor_id = motor_id
        self.motor = STS3032(port, 1000000)

        self.target_motor_angle = 0.0
        self.current_motor_angle = 0.0

        self.target_motor_torque = 0  # -1000 ~ +1000

        self.current_motor_load = 0.0
        self.max_width = 31.5  # mm
        self.angle_range = (0.0, 0.0)
        self.enabled = False
        self.to_set_enable = False
        self.mode = mode

    def setup(self):
        self.calibration()

        print("Entering RT loop...")

        self.set_mode(self.mode)

        super().setup()

    def loop(self):
        read_motor_angle, _, _ = self.motor.read_angle(self.motor_id)
        if read_motor_angle != None:
            self.current_motor_angle = read_motor_angle
        # load, direction, _, _ = self.motor.read_load(self.motor_id)
        # self.current_motor_load = direction * load

        if self.to_set_enable != self.enabled:
            if self.to_set_enable:
                self.motor.enable_torque(self.motor_id)
                self.enabled = True
            else:
                self.motor.disable_torque(self.motor_id)
                self.enabled = False
        if self.enabled == True:
            if self.mode == "pos":
                self.motor.write_angle(self.motor_id, self.target_motor_angle)
            elif self.mode == "torque":
                self.motor.write_torque(
                    self.motor_id, self.target_motor_torque)
            elif self.mode == "disable":
                self.motor.write_torque(
                    self.motor_id, self.target_motor_torque)
            else:
                print(f"[Error] Unknown mode: {self.mode}")

    def shutdown(self):
        super().shutdown()
        self.motor.disable_torque(self.motor_id)
        self.motor.close()
        print("Gripper shutdown and motor released.")

    def set_enable(self):
        self.to_set_enable = True
        return

    def set_disable(self):
        self.to_set_enable = False
        return

    def set_mode(self, mode: str):
        """
        switch mode to "pos" or "torque", "disable"
        """
        if mode not in ["pos", "torque", "disable"]:
            print(f"[Warning] Unsupported mode={mode}, defaulting to pos.")
            mode = "pos"

        self.mode = mode
        if self.mode == "pos":
            self.motor.set_max_torque(self.motor_id, 500)
            self.motor.set_control_mode(self.motor_id, 0)
            self.motor.enable_torque(self.motor_id)
            self.to_set_enable = True
            self.enabled = True
            print("[Info] Switched to Position Mode")
        elif self.mode == "disable":
            self.motor.set_control_mode(self.motor_id, 2)
            self.motor.disable_torque(self.motor_id)
            self.to_set_enable = False
            self.enabled = False
            print("[Info] Switched to Torque disable Mode")
        else:
            self.motor.set_control_mode(self.motor_id, 2)
            self.motor.enable_torque(self.motor_id)
            self.to_set_enable = True
            self.enabled = True
            print("[Info] Switched to Torque Mode")

    def set_angle(self, angle_deg: float):
        min_angle, max_angle = self.angle_range
        clamped_angle = max(min(angle_deg, max_angle), min_angle)
        if angle_deg != clamped_angle:
            print(
                f"[Warning] angle={angle_deg:.2f}° out of range, clamped to {clamped_angle:.2f}°")
        self.target_motor_angle = clamped_angle

    def set_torque(self, torque_val: int):
        torque_val = max(min(torque_val, 1000), -1000)
        self.target_motor_torque = torque_val

    def get_current_angle(self):
        return self.current_motor_angle

    def get_current_load(self):
        return self.current_motor_load

    def get_current_pos(self):
        _, max_angle = self.angle_range
        if max_angle <= 0:
            return 0.0
        pos = (self.current_motor_angle / max_angle) * self.max_width
        pos = max(0.0, min(pos, self.max_width))
        return pos

    def set_pos(self, pos_mm: float):
        pos_mm = max(0.0, min(pos_mm, self.max_width))
        _, max_angle = self.angle_range
        if max_angle <= 0:
            print("[Warning] angle_range invalid. Calibration not done yet?")
            return
        angle_deg = (pos_mm / self.max_width) * max_angle
        self.set_angle(angle_deg)

    def _wait_until_stall(self, direction: int, step_deg=2.0, stall_duration=1.0):
        while True:
            read_last_angle, _, _ = self.motor.read_angle(self.motor_id)
            if read_last_angle != None:
                target_angle = read_last_angle
                last_angle = read_last_angle
                unchanged_time = 0.0
                break

        while True:
            target_angle += direction * step_deg
            target_angle = max(min(target_angle, 180), -180)
            self.motor.write_angle(self.motor_id, target_angle)
            time.sleep(1.0 / self.freq)

            read_current_angle, _, _ = self.motor.read_angle(self.motor_id)
            if read_current_angle == None:
                continue
            else:
                current_angle = read_current_angle

                if abs(current_angle - last_angle) < 0.5:
                    unchanged_time += 1.0 / self.freq
                else:
                    unchanged_time = 0.0
                last_angle = current_angle

                if unchanged_time >= stall_duration:
                    return current_angle

    def calibration(self):
        print("== Delta6Gripper Calibration ==")
        self.motor.set_control_mode(self.motor_id, 0)  # 强制进入位置模式做校准
        self.motor.set_max_torque(self.motor_id, 500)
        time.sleep(0.2)

        self.motor.enable_torque(self.motor_id)
        time.sleep(0.2)

        self._wait_until_stall(direction=-1)
        self.motor.reset_zero(self.motor_id)
        time.sleep(0.2)
        print(f"Limit 1: 0.00°")

        angle2 = self._wait_until_stall(direction=1)
        print(f"Limit 2: {angle2:.2f}°")

        self.motor.disable_torque(self.motor_id)
        self.motor.set_max_torque(self.motor_id, 1000)

        self.angle_range = (0.0, abs(angle2))
        print(f"Gripper calibrated. Range: {self.angle_range}")
        self.set_angle(abs(angle2))


if __name__ == "__main__":
    gripper = Delta6GripperController(
        motor_id=1, port='COM8', freq=10, mode="torque")
    gripper.print_frequency = True
    gripper.setup()

    print("Main thread started loop_spin()...")
    gripper.loop_spin()

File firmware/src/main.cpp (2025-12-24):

#include <SPI.h>
#include <ercks.h>
#include <EEPROM.h>  // Include the EEPROM library

/* ercks Rotary Position Sensors */
const byte csPins[6] = {3, 4, 5, 6, 7, 8};         // Array of CS pins for 6 sensors
const byte mosiPins[6] = {19, 18, 17, 16, 15, 14}; // Each sensor's corresponding MOSI pin
byte pinSCK = 2;                                   // Shared SCK pin

ercks sensors[6]; // Create 6 ercks sensor objects

#define START_BYTE 0xAA
#define CMD_CALIBRATION 0x01
#define CMD_READ 0x02

int calibrationOffsets[6] = {0}; // Stores calibration offset for each sensor
int positions[6] = {0};          // Stores current position for each sensor
uint8_t errorFlags = 0;          // Error flag byte

// Function declarations (function prototypes)
void processSerial();
uint8_t calculateChecksum(uint8_t *data, uint8_t length);
void handleCalibration();
void handleRead();
void updatePositions();

void setup() {
  Serial.begin(115200);

  // Load calibration offsets from EEPROM
  for (int i = 0; i < 6; i++) {
    EEPROM.get(i * sizeof(int), calibrationOffsets[i]); // Read calibration offsets from EEPROM
  }

  // Initialize each sensor
  for (int i = 0; i < 6; i++) {
    sensors[i].attach(csPins[i], pinSCK, mosiPins[i]);
  }

  //Serial.println("6x ercks Rotary Position Sensors Initialized");
}

void loop() {
  processSerial();    // Process serial commands
  updatePositions();  // Update sensor position data
  delay(10);          // Small delay
}

// Process serial data
void processSerial() {
  static enum { WAIT_START, READ_CMD, READ_CHECKSUM } state = WAIT_START;
  static uint8_t cmd;
  static uint8_t checksum;

  while (Serial.available()) {
    uint8_t byte = Serial.read();
    switch (state) {
      case WAIT_START:
        if (byte == START_BYTE) {
          state = READ_CMD;
        }
        break;
      case READ_CMD:
        cmd = byte;
        state = READ_CHECKSUM;
        break;
      case READ_CHECKSUM:
        checksum = byte;
        // Verify checksum
        uint8_t calcChecksum = calculateChecksum(&cmd, 1);
        if (checksum == calcChecksum) {
          // Process command
          if (cmd == CMD_CALIBRATION) {
            handleCalibration();
          } else if (cmd == CMD_READ) {
            handleRead();
          }
        }
        // Reset state regardless of checksum verification result
        state = WAIT_START;
        break;
    }
  }
}

// Calculate checksum (simple sum)
uint8_t calculateChecksum(uint8_t *data, uint8_t length) {
  uint8_t sum = 0;
  for (uint8_t i = 0; i < length; i++) {
    sum += data[i];
  }
  return sum;
}

// Handle calibration command
void handleCalibration() {
  // Read current position as calibration offset
  for (int i = 0; i < 6; i++) {
    int angle = sensors[i].readAngle();
    if (angle == -1) {
      errorFlags |= (1 << i);        // Set error flag for corresponding sensor
      calibrationOffsets[i] = 0;     // Set offset to 0 if an error occurs
    } else {
      calibrationOffsets[i] = angle; // Save calibration offset
      EEPROM.put(i * sizeof(int), calibrationOffsets[i]); // Store offset in EEPROM
    }
  }
  // Optionally, send confirmation to the host
}

// Handle read command
void handleRead() {
  // Prepare response packet
  uint8_t packet[1 + 6 * 2 + 1 + 1]; // Start byte + data + error flag + checksum
  uint8_t idx = 0;
  packet[idx++] = START_BYTE;

  // Add position data for each sensor (considering calibration offset)
  for (int i = 0; i < 6; i++) {
    int16_t adjustedAngle = positions[i] - calibrationOffsets[i];
    packet[idx++] = (adjustedAngle >> 8) & 0xFF; // High byte
    packet[idx++] = adjustedAngle & 0xFF;        // Low byte
  }

  // Add error flag byte
  packet[idx++] = errorFlags;

  // Calculate checksum
  uint8_t checksum = calculateChecksum(&packet[1], idx - 1); // Exclude start byte
  packet[idx++] = checksum;

  // Send data packet
  Serial.write(packet, idx);

  // Clear error flags after sending
  errorFlags = 0;
}

// Update sensor position data
void updatePositions() {
  for (int i = 0; i < 6; i++) {
    int angle = sensors[i].readAngle();
    if (angle == -1) {
      errorFlags |= (1 << i); // Set error flag for corresponding sensor
      positions[i] = 0;       // Set position to 0 if an error occurs, or handle as needed
    } else {
      positions[i] = angle;   // Update position data
    }
  }
}

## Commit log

2025-06-16 initial upload
    [arm_mount.STL, bearing_housing_roll_pitch.STL, bearing_housing_xyz.STL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]
2025-07-11 improve gripper rt
2025-07-11 update calibration
